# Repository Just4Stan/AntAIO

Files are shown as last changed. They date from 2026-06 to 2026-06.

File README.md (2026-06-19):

# AntAIO

Open-source **antweight / beetleweight combat-robot all-in-one** controller — an
ExpressLRS receiver, a 6-axis IMU, and a **triple brushed-DC ESC** on one tiny
board, in the spirit of the [Malenki Nano](https://turnabot.com/products/malenki-nano-integrated-6-channel-triple-electronic-speed-controller-receiver-combo). Built on
the **OpenRX-Lite** ELRS core (ESP32-C3 + SX1281, 2.4 GHz) and forked from
[`incutec-hw/OpenRX`](https://github.com/incutec-hw/OpenRX).

<p align="center">
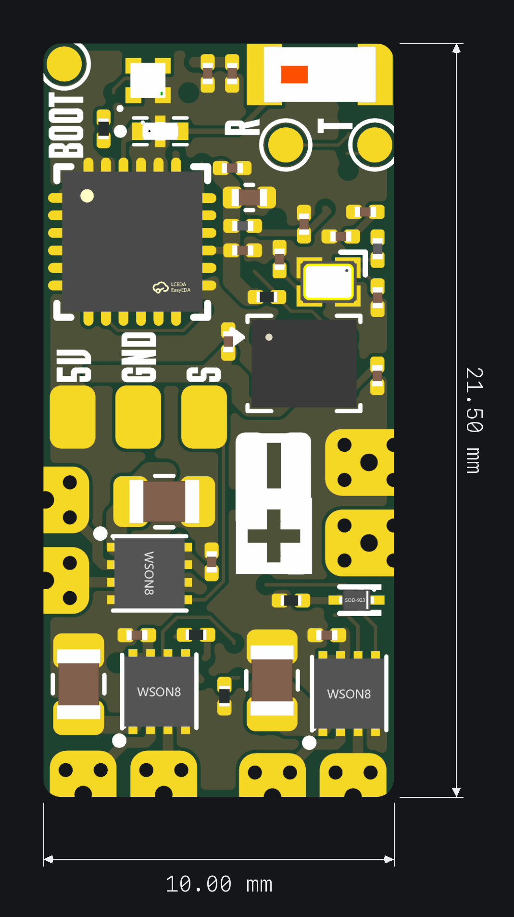
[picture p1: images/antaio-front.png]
AntAIO front
  
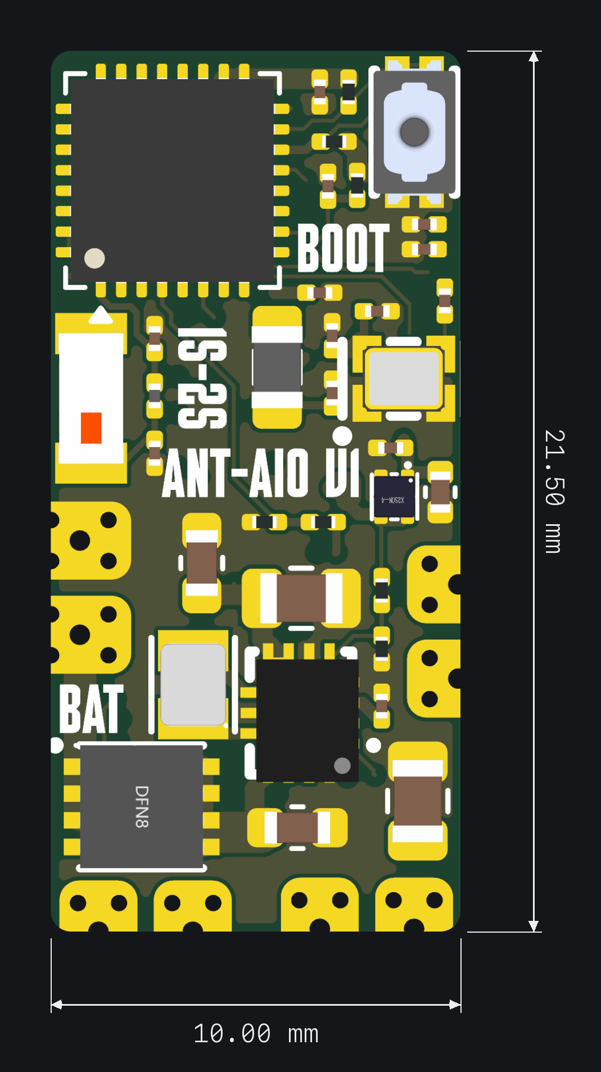
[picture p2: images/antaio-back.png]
AntAIO back
  
</p>

> [!WARNING]
> **Prototype — not validated, not fab-ready.** This board has open
> safety-critical issues (uncommanded drive-motor motion at power-up, and the
> programming interface shares pins with the motor outputs). It drives combat-robot
> motors **including a weapon** — do not build or power it without reading the
> review first. See **[hardware/REVIEW.md](hardware/REVIEW.md)** (full design
> review) and **[CHANGELIST.md](CHANGELIST.md)** (verified to-do list).

## What it is

A single **10.00 × 21.50 mm**, 6-layer board that replaces the usual *RX + 2 drive ESCs +
weapon ESC + gyro* stack of an antweight robot with one MCU-driven combo:

- **Radio link** — ExpressLRS 2.4 GHz (Semtech SX1281) for RC control + telemetry,
  plus the ESP32-C3's own Wi-Fi for OTA config.
- **Motion sensing** — LSM6DS3TR-C 6-axis IMU (gyro + accel) for heading-hold /
  self-right / melty-style control in firmware.
- **Three brushed-DC motor channels** — two drive + one weapon, each a TI DRV8212
  H-bridge fed directly from the battery.
- **Single-cell-friendly power** — buck-boost holds a 5 V rail as the pack sags
  under weapon load, with a linear 3.3 V logic rail and reverse-polarity protection.

Everything is controlled by the **ESP32-C3**: RC decode, mixing, gyro stabilization,
and the three motor PWM outputs all run on-chip.

## Architecture

```
            +BATT (1–2S LiPo)
              │
        Q2  AON7407  ── reverse-polarity P-FET
              ├─────────────► VM ─► DRV8212 ×3 ─► LEFT / RIGHT drive + WEAPON motors
              │
        U8  TPS63070 buck-boost ─► +5V ─► U4 TLV75533 LDO ─► +3V3 (logic)
                                                              │
   ┌──────────────────────────────────────────────────────────┤
   │                                                            │
 U1 ESP32-C3 ──SPI──► U3 SX1281 (2.4 GHz ELRS) ─► FL1 BPF ─► link antenna
   │            └────► U2 LSM6DS3TR-C IMU                 ESP Wi-Fi ─► AE1
   ├── 3× PWM ─► DRV8212 IN/EN  (U6 LEFT, U10 RIGHT, U11 WEAPON)
   ├── ADC ──── VSENSE (battery voltage divider)
   └── GPIO ──► WS2812B status LED (D1)
```

## Specifications

| Block | Part | Notes |
|---|---|---|
| **MCU** | Espressif **ESP32-C3FH4** (U1, QFN-32) | RISC-V, 4 MB embedded flash, 2.4 GHz Wi-Fi |
| **Link radio** | Semtech **SX1281** (U3) | 2.4 GHz, internal DC-DC, 52 MHz TCXO (OSC1), BPF FL1 (2450FM07D0034T) → link antenna |
| **IMU** | **LSM6DS3TR-C** (U2) | 6-axis accel+gyro, 4-wire SPI on the shared radio bus, dedicated CS |
| **Motor drivers** | 3× TI **DRV8212DSGR** | U6 = LEFT drive, U10 = RIGHT drive, U11 = WEAPON; PH/EN mode; VM = +BATT |
| **Buck-boost** | TI **TPS63070** (U8) | +BATT → 5 V; holds the rail across the 1S–2S sag range |
| **LDO** | **TLV75533PDQNR** (U4) | 5 V → 3.3 V logic rail |
| **Reverse protection** | **AON7407** P-FET (Q2) | on +BATT |
| **Status LED** | WS2812B (D1) | addressable RGB |
| **Battery** | **1–2S LiPo (≤ 8.4 V)** | DRV8212 VM is 12 V abs-max — **2S is the hard ceiling; 3S destroys the drivers** |
| **Board** | 10.00 × 21.50 mm, 6-layer | components both sides |

## I/O pads

Solder pads carry the external interface (silk in parentheses):

| Pad | Net | Function |
|---|---|---|
| `+` / `–` | `+BATT` / `GND` | Battery in (1–2S) |
| `5U` | `+5V` | 5 V buck-boost output (servo / accessory) |
| `GND` | `GND` | Ground |
| `S` | GPIO | Signal / spare control pad |
| `BOOT` | GPIO 9 | Hold low at power-up for UART download mode |
| `R` / `T` | UART0 RX / TX | Flashing & serial console (also the right-drive lines — flash with motor battery OFF) |

Motor outputs (OUT1/OUT2 of each DRV8212) and the weapon channel land on the large
copper pads along the board edge.

## ESP32-C3 pin map (as currently drawn)

| GPIO | Pin | Function | GPIO | Pin | Function |
|---|---|---|---|---|---|
| 0 | 4 | VSENSE (battery ADC) | 8 | 14 | WS2812 LED *(strap)* |
| 1 | 5 | Radio DIO1 | 9 | 15 | BOOT *(strap)* |
| 2 | 6 | IMU CS *(strap)* | 10 | 16 | WEAPON_EN |
| 3 | 8 | Radio BUSY | 18 | 25 | LEFT_PH *(USB D−)* |
| 4 | 9 | SPI MOSI | 19 | 26 | LEFT_EN *(USB D+)* |
| 5 | 10 | SPI MISO | U0RXD | 27 | RIGHT_PH |
| 6 | 12 | SPI SCK | U0TXD | 28 | RIGHT_EN |
| 7 | 13 | Radio NSS | GND/EP | 33 | GND |

> [!IMPORTANT]
> The drive-motor enables currently sit on the USB (GPIO18/19) and UART0
> (U0RXD/U0TXD) pins, which are driven **high at reset** — enabling both drive
> motors before firmware runs. The planned fix re-maps PH↔EN onto reset-quiet pins
> and gates the H-bridges behind a default-off arm switch. **Do not treat this pin
> map as final** — track it in [CHANGELIST.md](CHANGELIST.md).

## Flashing

- **UART:** hold `BOOT` low, power-cycle, flash over the `R`/`T` (U0RXD/U0TXD) pads
  **with the motor battery disconnected** (these pins also drive the right motor).
- **Wi-Fi OTA:** ExpressLRS SoftAP, after an initial wired flash.

The ELRS link runs upstream **ExpressLRS** (`Unified_ESP32C3_2400_RX`, ≥ 3.5.0).
The combat-robot mixing, IMU stabilization, and motor-PWM control are application
firmware layered on top (separate; not in this hardware repo).

## Repository

AntAIO began as a fork of [`incutec-hw/OpenRX`](https://github.com/incutec-hw/OpenRX)
— the **OpenRX-Lite** ELRS core (ESP32-C3 + SX1281) extended into a combat-robot
all-in-one. The other OpenRX receiver variants are not part of this repo.

```
AntAIO/
├── hardware/             AntAIO board: ELRS RX + IMU + triple brushed ESC
│   ├── AntAIO.kicad_{pro,sch,pcb}
│   ├── esp32c3_sx1281_lite.kicad_sch   ELRS core sub-sheet
│   ├── REVIEW.md         full design review (pin/datasheet/electrical)
│   └── DESIGN.md
├── shared/libs/          project-local KiCad symbols / footprints / 3D models
├── shared/elrs-targets/  ExpressLRS hardware-target JSON
├── datasheets/common/    local datasheet cache
├── images/               board renders
└── CHANGELIST.md         verified open / done items
```

KiCad 9/10; **project-local libraries only** (no global dependencies). Board renders
are produced with the shared `render_board.py` tool (vias + solder paste stripped,
transparent square).

## License

Hardware: **CERN Open Hardware Licence Version 2 — Strongly Reciprocal**
([CERN-OHL-S-2.0](https://ohwr.org/cern_ohl_s_v2.txt)). See [LICENSE](LICENSE).
Firmware: MIT.

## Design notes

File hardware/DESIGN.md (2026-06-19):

# AntAIO — design summary

Antweight / beetleweight combat-robot all-in-one: ExpressLRS 2.4 GHz receiver +
6-axis IMU + triple brushed-DC ESC on one 10.00 × 21.50 mm, 6-layer board. Built
on the OpenRX-Lite ELRS core (ESP32-C3 + SX1281).

For the full part list, pin map, I/O pads and architecture see the top-level
[README](../README.md). For the verified open/done design issues see
[REVIEW.md](REVIEW.md) and [CHANGELIST.md](../CHANGELIST.md).

## Board preview

| Front | Back |
|---|---|
| Front | Back |

## Schematic

- Root sheet: `AntAIO.kicad_sch` → ELRS core sub-sheet `esp32c3_sx1281_lite.kicad_sch`
- RF chain: `SX1281 RFIO → 2450FM07D0034 (FL1, 2.4 GHz BPF) → link antenna`
- ESP32-C3 Wi-Fi → AE1 (2450AT18A100E) for OTA config
- Power: AON7407 reverse P-FET → TPS63070 buck-boost (+5 V) → TLV75533 LDO (+3V3)
- Motors: 3× DRV8212 H-bridge (2 drive + 1 weapon), VM = +BATT

## Firmware

- ELRS link target: `Unified_ESP32C3_2400_RX` (≥ 3.5.0)
- Hardware JSON: `../shared/elrs-targets/OpenRX Lite 2400.json`
- Combat-robot mixing / IMU stabilization / motor PWM are application firmware on
  top of ELRS (separate; not in this hardware repo)

## Flash interface

- Pads: `5V` (or `5U`), `GND`, `R`/`T` (U0RXD/U0TXD)
- `BOOT`: hold low at power-up for UART download mode
- Wi-Fi OTA after the first wired flash
- **Flash with the motor battery disconnected** — `R`/`T` are also the right-drive lines

## Sourcing

LCSC basic/preferred parts where possible. Key RF/active parts:

- `C2651081` 2450FM07D0034 — 2.4 GHz bandpass filter (FL1)
- `C2151551` SX1281IMLTRT — link radio (watch stock for volume runs)
- DRV8212DSGR ×3 — brushed H-bridges
- TPS63070RNMR — buck-boost; TLV75533PDQNR — 3.3 V LDO

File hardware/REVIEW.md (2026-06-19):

I have all the data I need in the prompt. Let me synthesize the final report directly.

# OpenRX-Lite (AntAIO) — Final Design Review

**Board:** OpenRX-Lite extended to integrated antweight/beetleweight combat-robot controller (ELRS 2.4 GHz RX + IMU + triple brushed-DC ESC).
**Verdict:** **NOT READY FOR FAB.** Multiple confirmed SEV1 issues, two of them safety-critical (uncommanded drive-motor motion at every boot/reset) and two that make the board effectively un-flashable. One real wiring defect (floating radio ground). A redesign of the ESP32-C3 pin-mux/motor-control scheme is required, not just resistor edits.

---

## 1. Executive Summary

The sensing, radio, IMU, power-conversion, clock, and RF-front-end subcircuits are largely correct and match reference designs. The fatal problems are concentrated in the **ESP32-C3 pin-mux for the three motor drivers** and the **programming/debug path**:

- The 16-GPIO-class ESP32-C3 (QFN-32, FH4) is **out of pins**. To wire 3×(PH+EN) motor control plus SPI(4) + radio(NSS/BUSY/DIO1) + IMU_CS + LED + BOOT + VSENSE, the design consumed **both** the native USB-Serial/JTAG pins (GPIO18/19) **and** UART0 (U0RXD/U0TXD). The result: no usable flashing/console interface, and two motor-enable lines that are forced HIGH at reset by the chip's own internal pull-ups.
- This produces **uncommanded LEFT and RIGHT drive-motor motion on every power-up, reset, and flash** — a safety-critical failure on a combat robot. The WEAPON channel, by contrast, defaults safe.
- One genuine wiring defect: **SX1281 pin 5 (GND) is floating.**
- A 5 V intermediate rail that exists only to feed a 3.3 V LDO (efficiency + thermal SEV2), a 2S-max battery ceiling set by the DRV8212 (SEV2), missing local VM decoupling on the drivers (SEV2), and assorted SEV3 robustness items round out the list.

**Readiness: Block fab. Resolve the SEV1 cluster (pin-mux/programming/boot-safety) with a control-scheme redesign or larger-pin/expander part, fix the floating radio ground, then re-review.**

---

## 2. SAFETY-CRITICAL — Uncommanded Motor/Weapon Motion

The dominant hazard. Confirmed by adversarial verification. PH/EN mode is selected on all three drivers (MODE = +3V3, DRV8212 Table 8-2). In PH/EN mode, **EN=1 drives the H-bridge; EN=0 = brake/Hi-Z** (Table 8-4). The DRV8212 inputs have only an internal ~100 kΩ pulldown (RPD). The ESP32-C3's internal pulls at reset overpower that 100 kΩ:

| Channel | EN net | ESP pin / reset state | EN node voltage at reset | Result |
|---|---|---|---|---|
| **LEFT drive (U6)** | LEFT_EN = U1.26 = **GPIO19 (USB D+)** | USB_PU (~1.5 kΩ FS pull-up) | 3.3·100k/101.5k ≈ **3.25 V** ≫ VIH 1.45 V | **ENABLED.** LEFT_PH=GPIO18 has a 50 µs HIGH power-up glitch (Table 2-2) → defined forward-then-reverse twitch |
| **RIGHT drive (U10)** | RIGHT_EN = U1.28 = **U0TXD** | WPU 45 kΩ + output-enabled (UART idles driven HIGH) | 3.3·100k/145k ≈ **2.28 V** > VIH 1.45 V; or driven push-pull HIGH | **ENABLED.** RIGHT_PH=U0RXD idles HIGH → sustained **Forward drive** |
| **WEAPON (U11)** | WEAPON_EN = U1.16 = **GPIO10** | IE only, no pull (Table 2-1); 5 ns LOW glitch | DRV 100 kΩ pulldown wins → **~0 V** | **DISABLED — SAFE** |

So **both drive motors are commanded ON, uncommanded, during the multi-ms window between reset release and firmware GPIO config**, on every power-up, brown-out recovery, watchdog reset, and flash cycle. RIGHT is the worst: U0TXD is actively driven high and the UART bitstream toggles the bridge (DRV tPD 135 ns ≪ one 115200-baud bit). The WEAPON channel is the only correctly-defaulting one (GPIO10 has no internal pull; PH hard-tied to GND).

**Note (correcting the original audit):** WEAPON_EN does **not** float and is **not** the dominant hazard — the original "floating weapon" framing was inverted. The weapon is safe by construction; the **drive** channels are the hazard.

**Why the simple fix is insufficient:** a 10 kΩ external pulldown on LEFT_EN cannot beat the ~1.5 kΩ USB_PU on GPIO19; on RIGHT_EN, 10 kΩ vs 45 kΩ WPU still leaves ~0.6 V (above VIL 0.4 V) and loses entirely when UART0 drives push-pull. **No pulldown wins against these pins.**

**Required fix (hardware, Stan-owned):**
1. **Re-map LEFT_EN and RIGHT_EN (and their PH lines) off the USB D+/D- and UART0 console pins** onto plain GPIOs that have no internal reset pull-up (mirror the GPIO10/WEAPON pattern), with external pulldowns sized to dominate the DRV 100 kΩ.
2. **Hard-gate all three H-bridges' VM (or VCC) through a load switch that defaults OFF** until firmware asserts a separate "motors-armed" GPIO that itself powers up low. Treat "all bridges disabled at reset" as a hardware guarantee, not firmware-dependent. (DRV8212 VCC can be GPIO-gated as an arm path per datasheet 8.4.2.)
3. Add an explicit external pulldown on **WEAPON_EN** too (defense-in-depth on a weapon line), and ensure firmware brown-out + ELRS link-loss failsafe forces every EN low within one frame.

---

## 3. SEV1 — Showstoppers

### SEV1-A — No usable programming/debug interface (USB and UART0 both consumed by motors)
**Refs/nets:** LEFT_PH=GPIO18(U1.25), LEFT_EN=GPIO19(U1.26) → U6; RIGHT_PH=U0RXD(U1.27), RIGHT_EN=U0TXD(U1.28) → U10.
**What's wrong:** GPIO18/19 are the ESP32-C3's **only** native USB-Serial/JTAG D-/D+; U0RXD/U0TXD are the **only** UART0 console/download pins. Both pairs drive motor inputs. There is no USB connector and no clean UART header (only test points TP1/TP2 tapping the right-motor nets). Consequences: (1) USB programming and JTAG debug are permanently unavailable; (2) the only remaining flash path is BOOT-button + UART0 over TP1/TP2 — which is shared with the right-drive DRV8212, so flashing twitches the wheel; (3) Wi-Fi OTA cannot do the first flash or recover a bricked bootloader/partition.
**Evidence:** ESP32-C3 datasheet Table 2-4 (GPIO18/19 = USB_D-/D+), Section 2.3.x (default USB-Serial/JTAG); lite.json net members above; no USB/UART bridge in inventory.
**Fix:** Reserve a real programming interface — free GPIO18/19 for USB-Serial/JTAG and add a USB-C connector or D+/D- pads; move LEFT motor elsewhere. Realistically the part is out of GPIO, so the genuine fix is **collapse the motor-control scheme** (single-pin sign-magnitude PWM per driver, or an SPI/I²C motor-driver expander) to free UART0 and/or USB, or move to a higher-pin-count MCU.

### SEV1-B — Boot-time UART0 traffic drives the RIGHT motor
**Refs/nets:** RIGHT_EN=U0TXD(U1.28)→U10.5, RIGHT_PH=U0RXD(U1.27)→U10.6.
**What's wrong:** U0TXD is in the After-Reset state WPU + output-enabled (Table 2-1, fn 8): UART0 TX idles actively-driven HIGH and follows any UART init, holding RIGHT_EN high (and U0RXD/PH high → Forward). Covered quantitatively in §2; called out separately because it removes the serial console as well.
**Correction to original audit:** the default ROM-message channel on ESP32-C3 is the **USB-Serial/JTAG controller, not UART0** (Section 2.6.2 / Table 2-12; UART printing requires EFUSE_DIS_USB_SERIAL_JTAG=1). So "the ROM prints to U0TXD and toggles RIGHT" is the wrong mechanism — but the enable-forced-high conclusion holds via the After-Reset output-enabled-high state and any firmware UART0 init.
**Fix:** Never place a motor enable on the UART0 console TX. Re-map RIGHT off U0RXD/U0TXD; keep UART0 free for CRSF/console.

### SEV1-C — SX1281 pin 5 (GND) floating
**Refs/nets:** U3.5 → single-node net `unconnected-(U3-GND-Pad5)`.
**What's wrong:** Pin 5 is a **dedicated die ground** (SX1281 datasheet Table 2-1, p.17), distinct from the exposed pad (pin 25). It sits between XTA(4) and XTB(6) — the reference-oscillator/PA guard ground. It is the only U3 ground pin left open (13/20/21/23/24 and EP are on GND). Floating it removes the local oscillator/PA ground return and shield, degrading phase noise, spurs, and EMC. ERC missed it because the custom symbol's pin 5 electrical type is `unspecified`.
**Fix:** Tie U3.5 to the GND net/plane and re-pour. Scope the fix to **pin 5 only** — XTB(6) NC is correct TCXO behavior, do not "fix" it. Set the symbol pin to power_in/passive so ERC catches this class of omission in future.

---

## 4. SEV2 — Major

### SEV2-A — 5 V intermediate rail serves nothing but the 3.3 V LDO
**Refs/nets:** `+5V` = [C37.1, C38.1, C39.1, R16.2, TP15.1, U4.3, U4.4, U8.7]. Only U4 (TLV75533 LDO) is a real load. Motors run from +BATT; all logic from +3V3.
**What's wrong:** Chain is +BATT → TPS63070 buck-boost → 5.0 V → linear LDO → 3.3 V. The LDO burns (5.0−3.3)/5.0 = **34% of all logic-rail energy** for no functional reason. TPS63070 output range is 2.5–9 V (it can regulate 3.3–4.0 V directly). Setpoint confirmed 4.98 V via R16=52.3k/R17=10k, VFB=0.8 V.
**Fix:** Retarget the buck-boost to **~3.8–4.0 V** (R16 ≈ 40k with R17=10k) to keep the LDO in regulation while cutting its loss ~4×, or set 3.3 V and delete the LDO (but then the SX1281 loses the LDO's RF supply filtering). **Note:** the original "~3.5 V" suggestion is too low — TLV75533 dropout is 238 mV max @500 mA and it is spec'd at VIN ≥ VOUT+0.5 V, so 3.5 V starves regulation/PSRR.

### SEV2-B — TLV75533 (1×1 mm X2SON-4) thermal margin on the shared 3V3 rail
**Refs:** U4 OUT=+3V3 feeds U1, U3, D1, U2, U6/U10/U11 VCC. RθJA = 168.4 °C/W (DQN).
**What's wrong:** Dropping 1.7 V at sustained current pushes Tj past the 125 °C recommended max in an enclosed combat ambient: ~290 mA @25 °C or ~250 mA @45 °C breaches 125 °C; 335 mA (ESP Wi-Fi TX @100% duty, Table 4-7) → Tj ~121 °C @25 °C / ~141 °C @45 °C. Risk of thermal foldback → MCU/radio brownout.
**Corrections to original audit:** thermal shutdown is ~165 °C (not 150 °C); RθJA is steady-state, so the real driver is **sustained** Wi-Fi TX during OTA/SoftAP config, not motor PWM transients — during live combat the ELRS link is RX-dominated (~84 mA), so the direct in-match link-loss coupling is weaker than originally stated. Still a real margin issue.
**Fix:** Lower LDO Vin to ~3.8–4.0 V (Pd drops ~4–8×) per SEV2-A, or move to the 2×2 mm DRV SON-6 package (RθJA 100.2 °C/W) with a generous thermal-pad pour; cap WS2812 brightness/duty. Re-verify Tj < 125 °C at real ambient.

### SEV2-C — No local 0.1 µF VM ceramic on any of the three drivers
**Refs/nets:** +BATT (=VM) carries only bulk: C31–C34/C42 = 22 µF, C35 = 10 µF. No 100 nF anywhere on +BATT; no per-VM local HF cap.
**What's wrong:** DRV8212 Table 8-1 / VM pin description mandates a 0.1 µF low-ESR ceramic VM→GND **at each device** plus bulk. Bulk MLCC at distance cannot damp VM ringing from the H-bridge edges; risk of VM overshoot toward the 12 V abs-max and false OCP/UVLO trips.
**Fix:** Add one 0.1 µF (X7R, ≥16 V) VM→GND at pin 1/pin 4 of **each** of U6/U10/U11, placed immediately at the pins. Also ensure a dedicated 0.1 µF CVCC at each driver's pin 8 (required for the DSG package) is placed locally. (VM abs-max is exactly 12 V, not 11.)

### SEV2-D — DRV8212 VM caps the pack at 2S; 3S overvolts all three drivers
**Refs:** U6.1/U10.1/U11.1 = +BATT = VM (direct, only Q2 in series).
**What's wrong:** DRV8212 VM = 11 V recommended / **12 V abs-max**. 3S LiPo at 12.6 V exceeds abs-max → driver damage. 2S (8.4 V) is within rating. The DRV8212 is the single binding limit — TPS63070 (16/20 V) and AON7407 (−20 V VDS) are not. **Correction:** an earlier note citing "AON7407 30 V" is wrong; it is a 20 V part. Brushed-motor stall/regen flyback and hot-plug inrush (VM transient ramp abs-max 2 V/µs) can push VM above 12 V even on a compliant 2S pack — the +BATT rail currently has no TVS.
**Fix:** Hard-label/spec **2S max (8.4 V)** in README/DESIGN and silkscreen. Add a +BATT TVS with standoff < 12 V (e.g. ~8.5–9 V working, SMBJ-class) and confirm bulk handles inductive flyback. For 3S support the DRV8212 must be replaced (e.g. DRV8220, 18 V — but 1 Ω RDS(on)).

### SEV2-E — ESP32-C3 symbol mislabels pins 4/5 as XTAL_32K_P/N instead of GPIO0/GPIO1
**Refs:** U1 pin4 (symbol name "XTAL_32K_P") = VSENSE; pin5 ("XTAL_32K_N") = DIO1.
**What's wrong:** Netlist binds by pin number so the connection is electrically correct (pin4 = GPIO0/ADC1_CH0, pin5 = GPIO1/ADC1_CH1; the 32 kHz names are alternate functions, no 32 kHz crystal is used). But the symbol pin names are misleading and a real review/maintenance hazard — a future spin could "fix" a non-bug or wire a real 32 kHz crystal there.
**Fix:** Rename the symbol pins to GPIO0/GPIO1 (or "GPIO0/XTAL_32K_P") in OpenRX-Shared.kicad_sym. Metadata-only; no netlist change.

---

## 5. SEV3 — Minor / Robustness / EMC

- **L1 24 nH series inductor in the XTAL_P leg (X1 40 MHz):** non-standard and asymmetric vs the reference two-cap oscillator. XTAL_P=[L1.2,U1.30] → C1(15 pF)+X1.1; XTAL_N=[C3.1,U1.29,X1.3]. The series L (and placing C1 on the crystal side, not the pin) shifts effective load capacitance and can reduce startup/negative-resistance margin on a safety-critical board. **Fix:** remove L1 (0 Ω), put 15 pF symmetric load caps directly at both XTAL_P/XTAL_N per Espressif reference; if L1 is deliberate (EMC), make it symmetric and verify startup margin. Load caps C1=C3=15 pF are otherwise correct for the CL=10 pF crystal.

- **SX1281 NRESET shares the ESP32-C3 EN reset RC** (CHIP_EN = [C28.1, R5.1, U1.7, U3.3]; R5=10k, C28=1µF, ~10 ms POR). Radio cannot be reset independently of the MCU; a wedged radio needs a full ESP power-cycle. NRESET has an internal 50 kΩ pull-up so the wired POR is valid. **Downgraded from SEV2 → SEV3:** functionally fine for ELRS, watchdog-reset recovers it, no motor path. **Fix:** set SX1281 reset=−1 in the ELRS target JSON and document the shared-reset choice; optionally route NRESET to a spare GPIO.

- **WEAPON_EN relies only on the DRV 100 kΩ internal pulldown** — no external pulldown on a weapon-arming line. **Downgraded from SEV2 → SEV3:** the default state is robustly off (DRV VIH=1.45 V needs ~14.5 µA to false-trip; not credible from ESP Hi-Z leakage; GPIO10 power-up glitch is LOW). Still worth a dedicated 4.7k–10k external pulldown at U11.5 as combat-robot best practice.

- **VSENSE node has no anti-alias/decoupling cap and ~8.4 kΩ source impedance.** VSENSE=[R11.1(52.3k),R12.2(10k),U1.4]; taps raw +BATT (shared with motor VM). High-Z + no filter → jittery ADC, possible nuisance LVC/failsafe trips. **Fix:** add 10–100 nF VSENSE→GND at the ADC pin (forms RC with the divider). Divider ratio 0.1605 is correct (2S→1.35 V, in ADC range).

- **TPS63070 COUT may dip below the 40 µF-effective floor after DC-bias derating.** C37(10µF/0603)+C38(22µF/0805)+C39(22µF/0805) = 54 µF nominal → ~30–40 µF effective at 5 V bias. **Fix:** match the datasheet 3×22 µF reference (swap C37 10µF→22µF) or use better DC-bias-retaining parts. Milder if rail is retargeted to ~3.8 V.

- **+BATT bulk thin / verify cap voltage rating.** ~120 µF nominal (heavily derated to ~40–80 µF effective at 8.4 V) shared by three H-bridges. Confirm C45783/C92487 are ≥16 V (preferably 25 V) rated for inductive transients; consider adding a low-ESR polymer/electrolytic at the +BATT entry for the weapon transient.

- **WS2812B (D1) VDD on +3V3 is below the 3.5 V datasheet minimum** (spec 3.5–5.5 V). 3.3 V is out-of-spec; clones usually light but color accuracy/internal-regulator behavior is unguaranteed. **Fix:** move D1 VDD to +5V — DIN direct from 3.3 V GPIO8 still meets VIH=2.8 V, no level shifter needed. *(Note: this is listed SEV2 in the source audit; rated SEV3 here as it is a status LED, not function-critical — but it is genuine out-of-spec operation, fix it.)*

- **WS2812B DIN has no series damping resistor.** R3 (10k to +3V3) is the GPIO8 boot strap, not a series term. Fine for a single short-stub LED; add ~47–100 Ω series in the DIN trace if EMI/edge integrity matters later (keep the 10k strap on the GPIO8 side).

- **VR_PA decoupled by single 10 nF (C27) vs reference 2×10 nF; DCC_FB second cap 10 nF (C26) vs reference 100 nF.** Add a parallel cap on VR_PA and change C26 → 100 nF to match the Semtech reference. Low priority.

- **TCXO (OSC1) VCC has no ferrite/dedicated local bypass; powered straight off the noisy shared +3V3.** SX1281 TCXO app note (Fig 15-3) shows a ferrite bead + 100 nF to keep digital/switcher noise off the 52 MHz reference (phase noise directly degrades RX). **Fix:** add a 600 Ω@100 MHz bead + local 100 nF at OSC1 VCC.

- **WSON-8 DRV8212 thermal ceiling ~2 A/channel continuous.** I²R = I²·0.28 Ω; at 3 A → ~2.5 W → TSD. OCP trips at 4 A (1.7 ms retry). Weapon/drive stall will OCP-cycle/TSD. **Fix:** dense thermal-via field under each EP, firmware current/PWM limits ~2 A/channel; for the weapon consider paralleling half-bridges (8 A) — requires Hi-Z MODE redesign.

- **L6 (1.5 µH 2016) Isat headroom thin vs 3.6 A switch limit** — acceptable only because the real 5 V load is light. Confirm Isat ≥ ~2.5 A when sourcing.

---

## 6. ELRS RF Front-End — Open Items (review-flagged, schematic-scope)

- **AE2 antenna BOM/doc mismatch + no matching network.** Netlist value for AE2 is `2450AT18A100E` (same as the Wi-Fi AE1), but README/CLAUDE.md state the Lite link antenna is the Molex **47948-0001**. Reconcile BOM vs docs. Net-(FL1-OUT)=[AE2.1, FL1.3] has **no matching components and no retune pads**, while the 2450AT18A100E datasheet explicitly requires a match (RL only 9.5 dB min). **Fix:** decide the real part and make the value field match; add a pi/L match footprint (0201 placeholders) on the FL1-OUT→antenna node; budget the loss into the link budget. *(Worth resolving but not a SEV1 — link still functions.)*

- **RFIO → FL1 direct (no series match/DC-block).** Acceptable: FL1's IN port is a 40 Ω chipset-matched port intended to mate with SX1281 RFIO directly, and the 2450FM07 is internally DC-blocked. Confirm against the Johanson app note / ELRS target, keep RFIO→FL1 trace short and impedance-controlled, and add FL1 IL (0.75–1.0 dB) to the link budget. If FL1 DC-pass is ever unconfirmed for a future grounded-feed antenna, add a series 100 pF C0G.

- **Two 2.4 GHz radios (ELRS link + ESP Wi-Fi), separate antennas, no RF switch.** Standard ELRS-RX approach; coexistence is firmware time-shared (Wi-Fi OTA-only). Maximize AE1/AE2 isolation in layout; document Wi-Fi as OTA-only in DESIGN.md.

---

## 7. Unconnected-Pin Disposition

| Pin(s) | Disposition |
|---|---|
| U1.19–24 (SPIHD/WP/CS0/CLK/D/Q) | **NC — correct.** In-package flash on ESP32-C3FH4; must not route externally |
| U2.4 INT1, U2.9 INT2 (IMU) | **NC — acceptable.** Polling-only; no spare GPIO for DRDY. For melty/heading-hold a hardware DRDY would give deterministic sampling — note as limitation |
| U2.10, U2.11 (IMU NC) | **NC — correct.** Datasheet: leave electrically unconnected, keep pads soldered |
| U3.5 (GND) | **DEFECT — must tie to GND.** See SEV1-C |
| U3.6 (XTB) | **NC — correct.** TCXO drives XTA via C19; second crystal terminal unused |
| U3.9 DIO2, U3.10 DIO3 | **NC — correct.** Optional radio DIO, unused by ELRS |
| U8.2 (PG) | **NC — acceptable.** Open-drain power-good; could optionally gate driver arm |
| D1.1 (DOUT) | **NC — correct.** Single WS2812, end of chain |
| AE1.2, AE2.2 | **NC — correct.** Single-feed chip-antenna ground/keep-out pads |
| GPIO20/GPIO21 (U0RTS/U0CTS) | **Unused — the only free pins.** Repurposing these is the lever to fix the pin-budget/programming-path problem |

---

## 8. Confirmed-Correct / INFO

- **Strapping pins GPIO2/GPIO8/GPIO9** all correctly biased (10k pull-ups to +3V3; BOOT button to GND): GPIO2(IMU_CS)=1, GPIO8(LED)=1, GPIO9(BOOT)=1 idle / 0 pressed → clean SPI boot, download only on button. R2 doubles as IMU CS idle-high and the GPIO2 strap; R3 doubles as the GPIO8 strap. **Ensure R2/R3/R4 are populated.**
- **CHIP_EN RC** = 10k(R5) × 1µF(C28) ≈ 10 ms POR, satisfies tSTBL/tRST(50 µs), not floating (datasheet requirement met).
- **VSENSE on GPIO0/ADC1_CH0** — valid ADC pin (ADC1 works with Wi-Fi on); divider 0.1605 keeps 1S–3S in the ATTEN3 0–2500 mV window; cell count bounded by DRV8212 VM, not the ADC.
- **LNA_IN Wi-Fi pi-match** (C22 1.2pF shunt / L2 2.5nH series / C21 1.2pF shunt) → AE1: canonical ESP32-C3 single-ended topology; tune on VNA.
- **L3 = Murata LQP03TN2N0B02D (2.0 nH RF inductor), correct** — the +3V3→L3→C25(1µF)→VDD3P3(pins 2,3) topology matches the Espressif analog/RF (Wi-Fi PA) reference. The "2N0" MPN decodes to 2.0 nH; **not** a mislabeled ferrite bead.
- **SX1281 SMPS mode** correct (VDD_IN tied to DCC_FB, L4 15µH on DCC_SW, 470nF on DCC_FB). **TCXO front-end** correct (52 MHz clipped-sine → C19 1nF AC-couple → XTA; XTB NC). **SPI shared bus** correct: MISO/MOSI/SCK shared SX1281+IMU+ESP, dedicated CS each, NSS 10k pull-up, IMU CS 10k pull-up — no contention, both slaves tri-state MISO when deselected (Semtech Fig 9-5 endorses this topology).
- **LSM6DS3TR-C** fully correct: 4-wire SPI not swapped (SDI←MOSI, SDO→MISO, SPC←SCK, CS←IMU_CS); aux-I²C SDx/SCx tied to GND (datasheet Mode-1); VDD/VDDIO on +3V3 with 100nF each (C15/C18); all node voltages within 4.8 V abs-max.
- **FL1 2450FM07D0034T** orientation correct (IN 40Ω→RFIO, OUT 50Ω→antenna, both GND pads grounded, internally DC-blocked).
- **Q2 AON7407 reverse-polarity P-FET** topology and gate network correct: source on battery B+, drain on +BATT load; R13 10k gate pulldown turns it on in normal use; **U7 6.2 V Zener correctly clamps VGS within the ±8 V abs-max** (required at 2S where unclamped VGS would be 8.4 V). *(See §9 — the "FET is backwards" claim is one investigator's contested finding.)*
- **5V→3V3 sequencing** correct (LDO EN tied to +5V, so 3V3 cannot precede 5V). TPS63070 EN via R15 100k to +BATT (always-on, within 20 V abs-max), PS/SYNC to GND via R14 (forced PWM, low ripple — good for RF), FB R16/R17 = 4.98 V, Vaux 100 nF.
- **DRV8212 MODE=+3V3 (PH/EN)** consistent on all three; **WEAPON PH=GND** is a sensible fixed-direction single-quadrant weapon drive; **EP→GND** on all three; OUT routing to motor pads correct.

---

## 9. Investigated — Not an Issue (dropped per verification)

- **"LEFT_PH GPIO18 50 µs glitch is a standalone SEV1 uncommanded-motion path."** **INVALID / demoted to INFO.** Per DRV8212 Table 8-4, EN=0 forces brake→Hi-Z with PH as don't-care, and PH has its own internal pulldown — a PH glitch alone causes no motion. The real hazard is the EN line (covered in §2). The 50 µs glitch only sets direction once EN is (separately) asserted.
- **"VDD_SPI (pin18) tied to +3V3 is a SEV2 topology/labeling risk."** **INVALID / demoted to INFO.** For the embedded-flash FH4, VDD_SPI is a backup-power **input** whose recommended input range (3.0/3.3/3.6 V) equals the rail; tying to +3V3 is the standard Espressif approach used in every C3 module. The "internal-LDO-shorted" scenario requires an off-package flash that does not exist (pins 19–24 unbonded). Residual: the symbol's `power_out` type for pin 18 is cosmetically imprecise (may trip a benign ERC warning) — optionally set to power_input/passive.
- **"Analog VDD3P3/VDDA decoupling SEV2 — L3 is a mislabeled ferrite bead."** **INVALID.** L3 is a genuine 2.0 nH RF inductor (Murata LQP03TN2N0B02D, see §8). The topology is the Espressif analog/RF reference. The only residue is a routine layout reminder (place a 100 nF adjacent to pins 2/3, 11, 17, 31/32) — INFO, not SEV2.
- **Q2 "FET is wired backwards / body diode defeats reverse protection" (one subcircuit investigator).** **Contested / not carried as a finding.** The dedicated Q2 pin-level audit and the power-tree audit both conclude the AON7407 orientation (source→battery B+, drain→+BATT load) with the R13 pulldown and 6.2 V Zener clamp is the correct high-side P-FET reverse-polarity/load-switch topology that blocks on reverse-connect. Given the majority pin-level verdict, this is not flagged as a defect — but it is the **one disagreement among reviewers**: before fab, Stan should confirm Q2 source/drain orientation against the AON7407 body-diode direction on the actual symbol/footprint, since a genuinely reversed P-FET would pass reverse current through the body diode. Low effort to verify, high consequence if wrong.

---

### Priority fix order
1. **Re-architect ESP32-C3 motor control** to free USB (GPIO18/19) and UART0 — single-pin sign-magnitude PWM or SPI/I²C motor expander, or larger MCU. This resolves SEV1-A/B and the §2 boot-drive hazard simultaneously.
2. **Hardware motor-disable / arm load switch** defaulting OFF (VM or VCC gated), plus external pulldowns on all three EN lines.
3. **Tie SX1281 pin 5 to GND** (SEV1-C).
4. Retarget buck-boost to ~3.8–4.0 V (SEV2-A/B); add per-driver 0.1 µF VM + VCC caps (SEV2-C); 2S-max label + +BATT TVS (SEV2-D); fix the symbol pin names (SEV2-E).
5. SEV3 cleanup: remove/symmetrize L1, VSENSE filter cap, WS2812 on +5V, TCXO bead, COUT match, reconcile AE2 BOM/docs + add match pads.

**Relevant files:** `hardware/AntAIO.kicad_sch`, `hardware/esp32c3_sx1281_lite.kicad_sch`, symbol library `shared/libs/OpenRX-Shared.kicad_sym` (SX1281 pin-5 type, ESP32-C3 pin4/5 names).

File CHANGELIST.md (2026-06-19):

# AntAIO — Verified Change List

1–2S antweight AIO (ESP32-C3 + SX1281 ELRS/ESPNOW, 4×N20 tank drive via 2 paired
DRV8212 + 1 weapon DRV8212, LSM6DS3 IMU). Forked from OpenRX-Lite.

Status as of 2026-06-18. Items below are **verified against the netlist** — open
items still need doing in KiCad; "already fixed" is for reference.

---

## OPEN — to do (in KiCad)

### 🔴 Critical
- [ ] **Swap PH↔EN on both drive drivers (boot-safety — motors run at power-on otherwise).**
  EN currently sits on pins driven HIGH at reset (USB D+ pull-up / UART TX), so the
  bridges enable before firmware. Move EN to the quiet pins, PH to the driven pins:
  - Left (U6):  **IN2/EN → GPIO18 (D-)**, **IN1/PH → GPIO19 (D+)**   *(swap of today's 19/18)*
  - Right (U10): **IN2/EN → GPIO20 (U0RXD)**, **IN1/PH → GPIO21 (U0TXD)** *(swap of today's 21/20)*
  - Weapon (U11) already safe (EN=GPIO10, no pull) — leave it.
  - Update the firmware target pin map to match after the swap.
- [ ] **Tie SX1281 (U3) pin 5 GND → GND** (currently floating; ERC missed it — pin type unspecified).

### 🟠 Important
- [ ] **Add a local 0.1 µF on each driver's VM and VCC** — U6, U10, U11 (6 caps total),
  placed at the pins. Today only distant bulk on +BATT.
- [ ] **Add a TVS on +BATT** (~9 V standoff, <11 V clamp) for inductive spikes / mis-plug.
  DRV8212 VM is 2S-max — **document the board as 2S-max** (3S destroys all drivers).
- [ ] **Add 2 UART flashing pads: GPIO20 (U0RXD) + GPIO21 (U0TXD).** With the existing
  BOOT button + GND (TP7) + a 3V3 tap, that's a full flash path (hold BOOT, power-cycle).
  Flash with motor battery OFF — these pins are also the right-drive lines.

### 🟡 Verify / minor
- [ ] **Add 100 nF on the VSENSE node → GND** (GPIO0). Today unfiltered + ~8 kΩ high-Z into the ADC.
- [ ] **Reconcile the ELRS antenna (AE2)** — netlist has `2450AT18A100E`, docs say Molex
  `47948-0001`, and there's **no match network**. Pick one and add the matching network.
- [ ] (cosmetic) ESP32-C3 symbol labels pins 4/5 as `XTAL_32K` — they are GPIO0/GPIO1. Relabel for clarity.

---

## Already fixed (verified in schematic)
- ✅ P-FET Q2 orientation correct (battery→Source, loads→Drain, Zener clamp on battery side).
- ✅ 3× DRV8212 placed + wired (2 drive paired, 1 weapon); MODE→3V3 (PH/EN); weapon PH→GND.
- ✅ SX1281 NRESET → CHIP_EN (radio resets with MCU; `radio_rst` undefined in firmware — confirmed safe in ELRS source).
- ✅ IMU SDO/SA0 → MISO (was on MOSI); shared SPI bus, CS=GPIO2, NSS=GPIO7.
- ✅ Power tree: AON7407 reverse P-FET → TPS63070 buck-boost → 5 V → TLV75533 LDO → 3V3.
  FB 52.3k/10k ≈ 5.0 V; EN pull-up; PS/SYNC→GND (forced PWM); VAUX cap; FB2→GND (datasheet-OK).
- ✅ VSENSE divider 52.3k/10k → GPIO0 (ADC). NSS pull-up (10k→3V3) on GPIO2 strapping.

## Decisions (do NOT change)
- **Keep the 5 V rail at 5 V.** It powers the servo/BLDC weapon output — do not retarget the
  buck-boost to ~4 V (the ~34 % LDO loss is small in absolute terms at ~0.4 A logic).
- **LDO thermal:** fine for ELRS (WiFi off). For **ESPNOW mode** (continuous WiFi) the 1×1 mm
  TLV75533 runs warm dropping 5→3.3 V — give it copper pour; no part change needed.
- **VSENSE stays on GPIO0, IMU_CS on GPIO2** — GPIO0 is the only non-strapping ADC pin; a divider
  on the GPIO2 strapping pin would break boot.

## Reference — final 15-pin map (ESP32-C3)
`0`=VSENSE · `1`=DIO1 · `2`=IMU_CS(+pull-up) · `3`=BUSY · `4`=MOSI · `5`=MISO · `6`=SCK ·
`7`=NSS · `8`=WS2812 · `9`=BOOT · `10`=WEAPON_EN · `18/19`=Left EN/PH* · `20/21`=Right EN/PH* ·
SX1281 RST→CHIP_EN. *(EN/PH order flips after the boot-safety swap above.)*

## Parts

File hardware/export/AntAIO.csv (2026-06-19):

Reference | Qty | Value | DNP | Exclude from BOM | Exclude from Board | Footprint | Datasheet | LCSC Part | LCSC Part_1 | LCSC
AE1 | 1 | 2450AT18A100E |  |  |  | OpenRX-Shared:ANT-SMD_L3.2-W1.6 | https://lcsc.com/product-detail/RF-Antenna_JOHANSON_2450AT18A100E_2450AT18A100E_C89334.html | C89334 |  | C89334
AE2 | 1 | 47948-0001 |  |  |  | OpenRX-Shared:ANT-SMD_47948-0001 | https://lcsc.com/product-detail/RF-Antenna_MOLEX_47948-0001_47948-0001_C152351.html | C152351
C1,C3 | 2 | 15pF |  |  |  | Capacitor_SMD:C_0201_0603Metric |  | C85891 |  | C85891
C4,C10,C15,C23,C25,C28 | 6 | 1uF |  |  |  | Capacitor_SMD:C_0201_0603Metric |  | C76935 |  | C76935
C5,C6,C9,C12,C13,C14,C17 | 7 | 100nF |  |  |  | Capacitor_SMD:C_0201_0603Metric |  | C76939 |  | C76939
C8,C11,C16 | 3 | 10uF |  |  |  | Capacitor_SMD:C_0402_1005Metric |  | C15525 |  | C15525,C76991
C19 | 1 | 1nF |  |  |  | Capacitor_SMD:C_0201_0603Metric |  | C66942 |  | C66942
C20 | 1 | 470nF |  |  |  | Capacitor_SMD:C_0201_0603Metric |  | C85926 |  | C85926
C21,C22 | 2 | 1.2pF |  |  |  | Capacitor_SMD:C_0201_0603Metric |  |  |  | C85895
C24,C26,C27 | 3 | 10nF |  |  |  | Capacitor_SMD:C_0201_0603Metric |  | C2168164 |  | C2168164
D1 | 1 | XL-1010RGBC-WS2812B |  |  |  | OpenRX-Shared:LED-SMD_4P-L1.0-W1.0-TL_XL-1010RGBC-WS2812B |  | C5349953
FL1 | 1 | 2450FM07D0034T |  |  |  | OpenRX-Shared:FILTER-SMD_4P-L1.0-W0.5-L | https://www.lcsc.com/datasheet/C2651081.pdf | C2651081 | C2651081
L1 | 1 | 24nH |  |  |  | Inductor_SMD:L_0201_0603Metric |  | C206441 |  | C206441
L2 | 1 | 2.5nH |  |  |  | Inductor_SMD:L_0201_0603Metric |  |  |  | C206435
L3 | 1 | 2.0nH |  |  |  | Inductor_SMD:L_0201_0603Metric |  |  |  | C86125
L4 | 1 | 15uH |  |  |  | Inductor_SMD:L_0805_2012Metric
OSC1 | 1 | OW7EL89CENUNFAYLC-52M |  |  |  | OpenRX-Shared:OSC-SMD_4P-L2.0-W1.6-BL_TXC_7Z |  | C22434896 |  | C22434896
R2,R3,R4,R5 | 4 | 10k |  |  |  | Resistor_SMD:R_0201_0603Metric |  | C106225 |  | C106225
TP1 | 1 | RX |  |  |  | OpenRX-Shared:SolderPad_1.2x2.0mm
TP2 | 1 | TX |  |  |  | OpenRX-Shared:SolderPad_1.2x2.0mm
TP3 | 1 | 5V |  |  |  | OpenRX-Shared:SolderPad_1.2x2.0mm
TP4 | 1 | GND |  |  |  | OpenRX-Shared:SolderPad_1.2x2.0mm
TP5 | 1 | BOOT |  |  |  | OpenRX-Shared:SolderPad_1.2x2.0mm
U1 | 1 | ESP32-C3 |  |  |  | Package_DFN_QFN:QFN-32-1EP_5x5mm_P0.5mm_EP3.7x3.7mm | https://www.espressif.com/sites/default/files/documentation/esp32-c3_datasheet_en.pdf
U2 | 1 | TLV75533PDQNR |  |  |  | OpenRX-Shared:X2SON-4_L1.0-W1.0-P0.65-TL-EP |  | C2861882 |  | C2861882
U3 | 1 | SX1281IMLTRT |  |  |  | OpenRX-Shared:QFN-24_L4.0-W4.0-P0.50-TL-EP2.6 |  | C2151551 |  | C2151551
X1 | 1 | CJ17-400001010B20 |  |  |  | OpenRX-Shared:CRYSTAL-SMD_4P-L1.6-W1.2-BL |  | C2875272 |  | C2875272

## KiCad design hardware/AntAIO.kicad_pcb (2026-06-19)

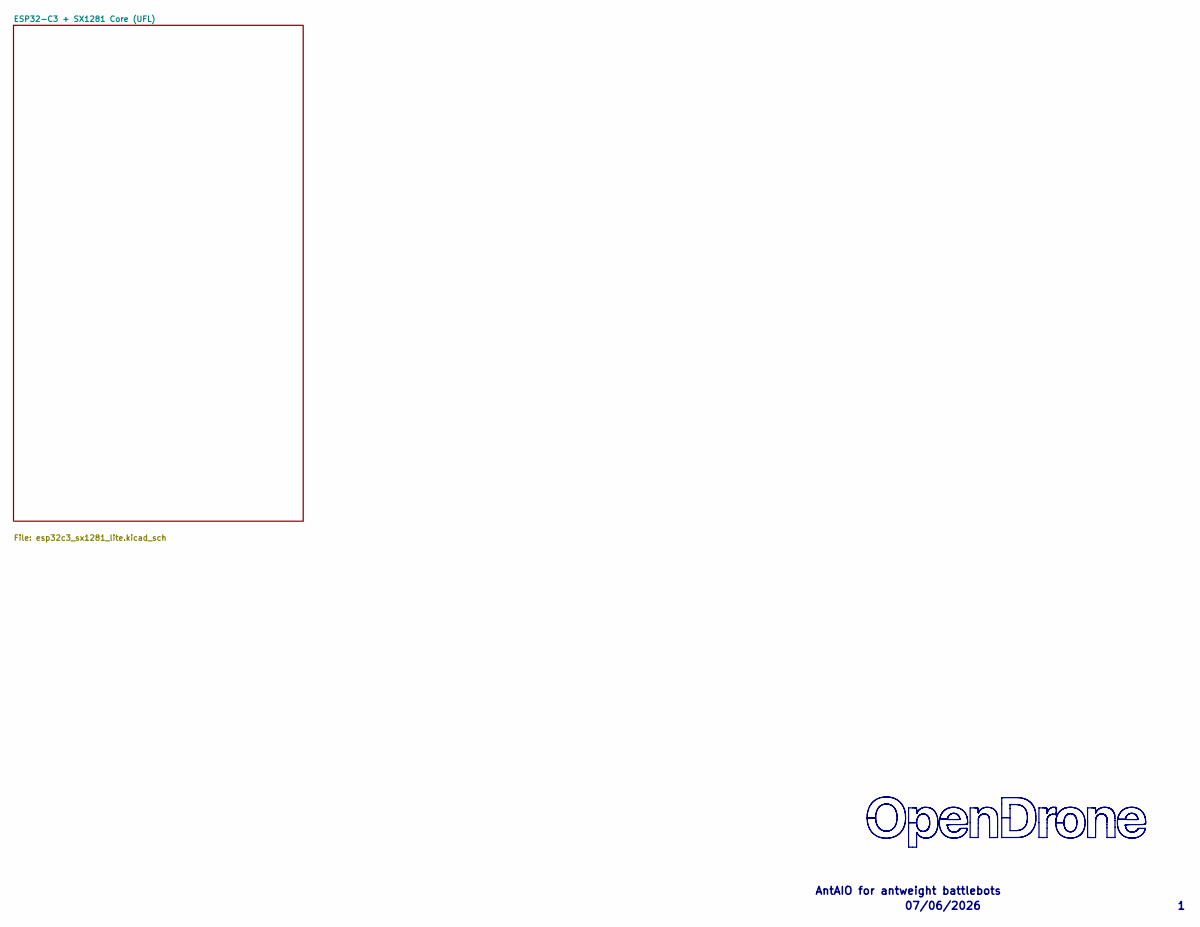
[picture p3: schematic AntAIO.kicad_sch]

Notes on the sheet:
07/06/2026
AntAIO for antweight battlebots

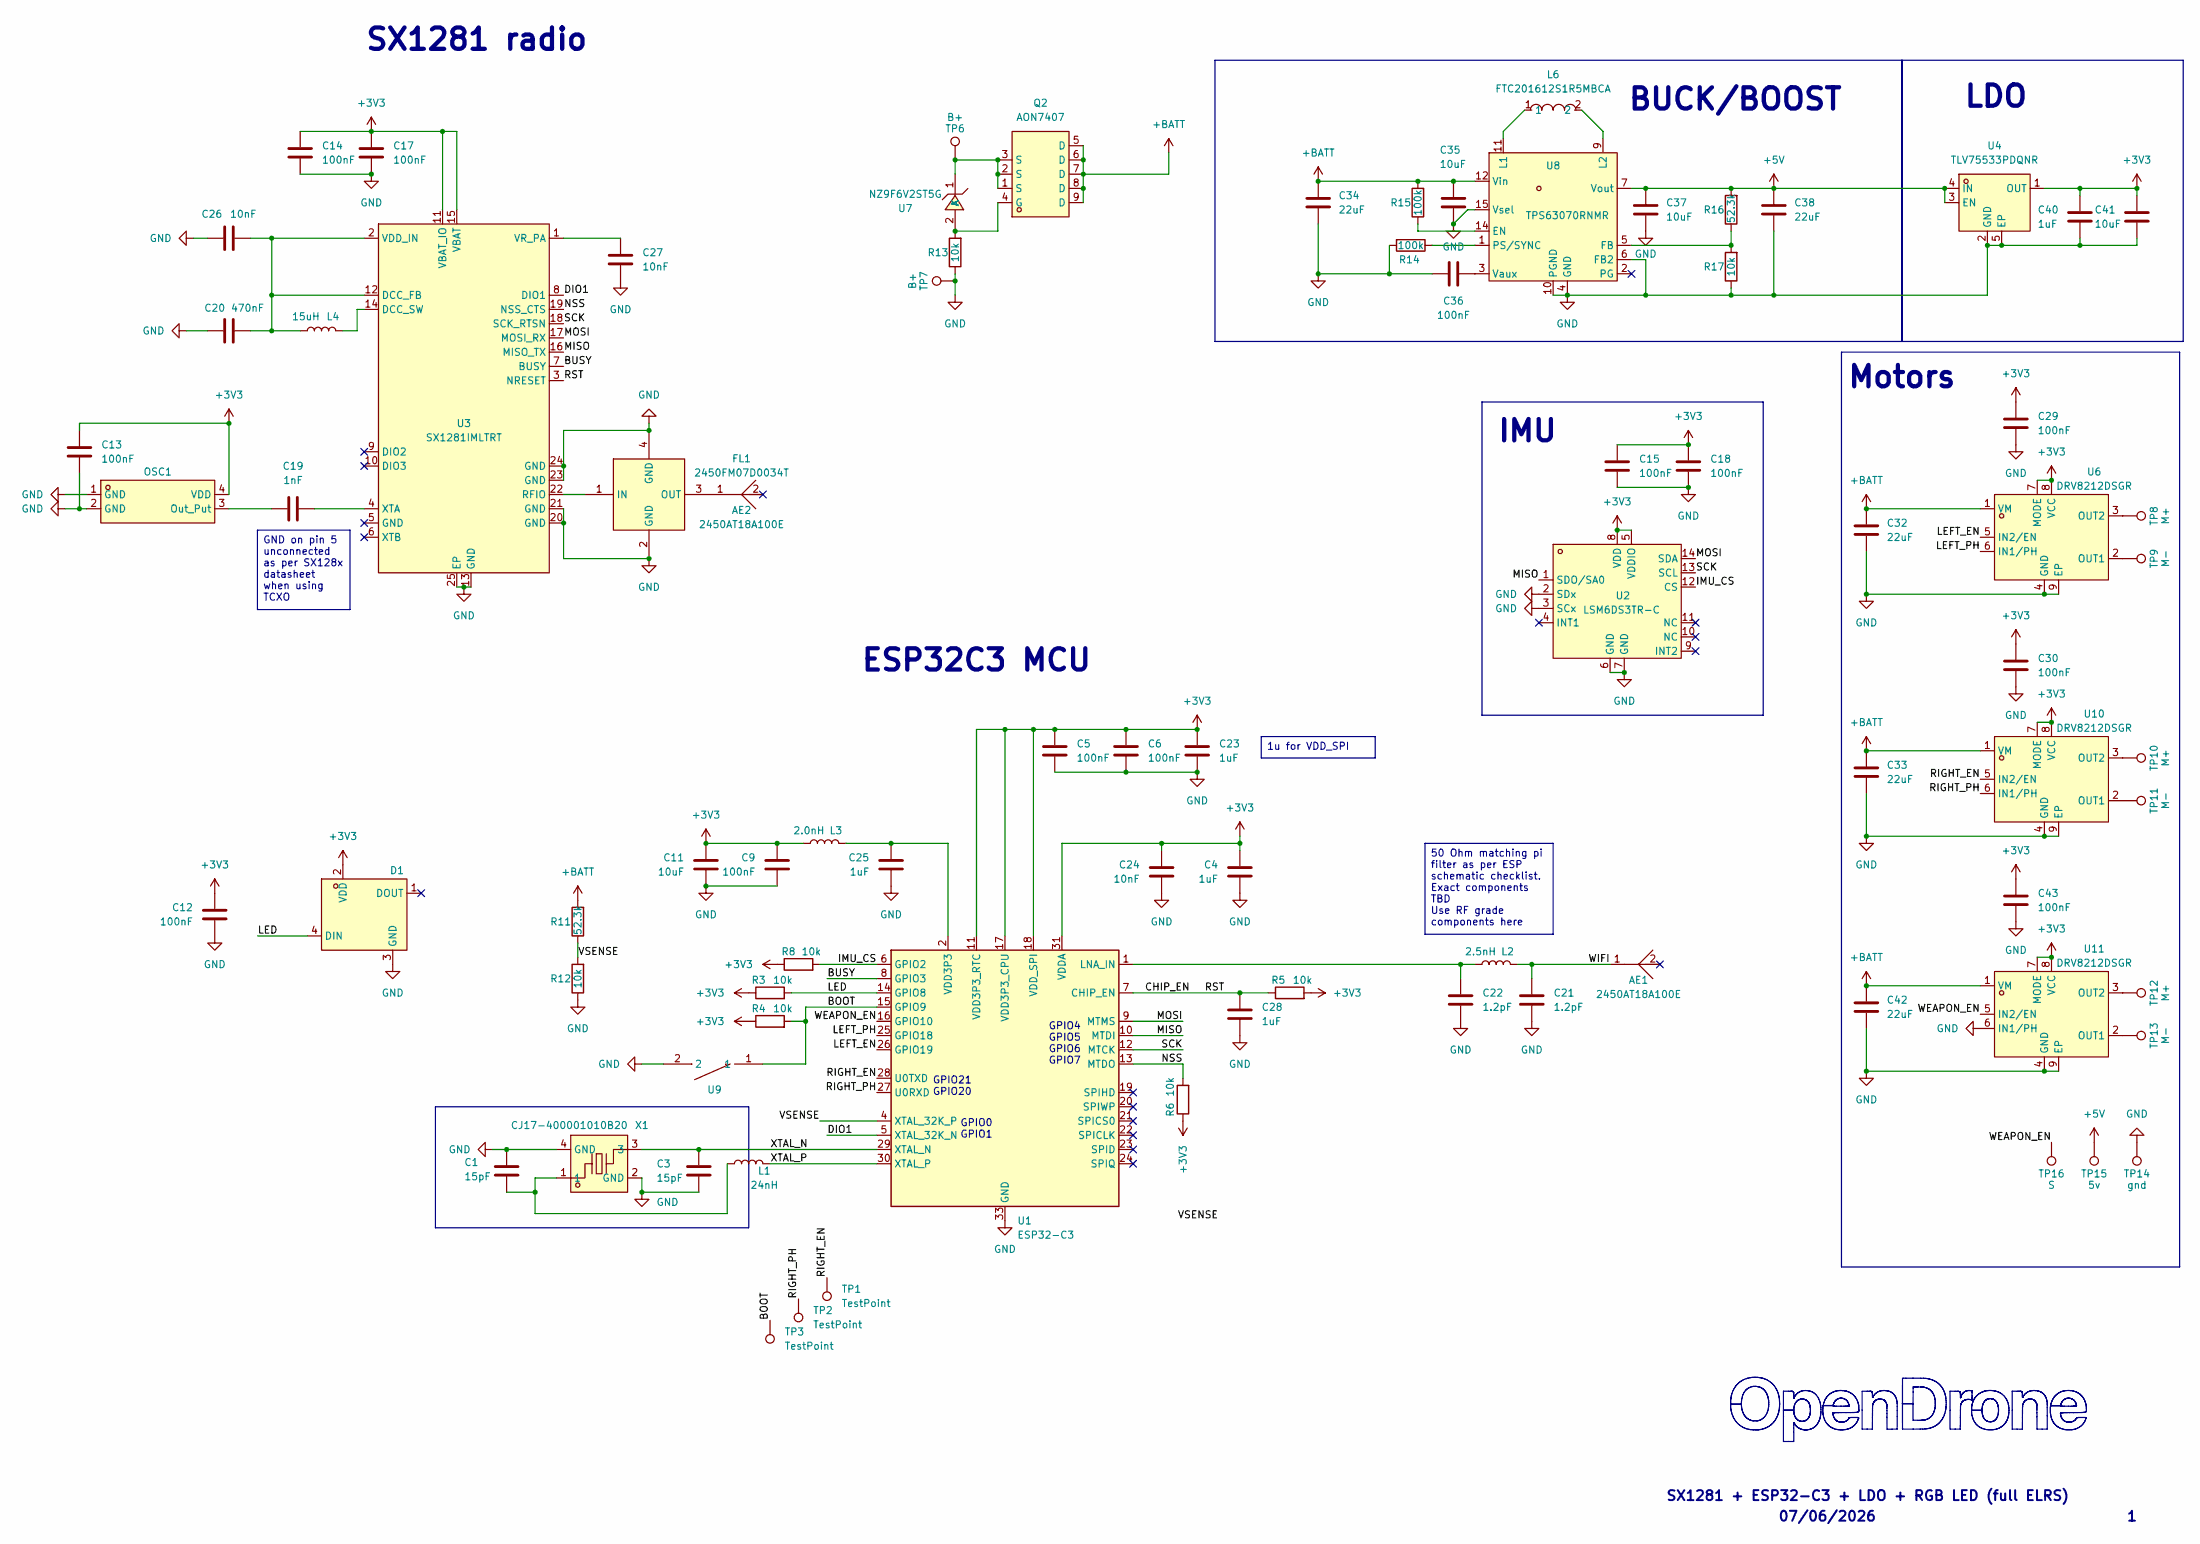
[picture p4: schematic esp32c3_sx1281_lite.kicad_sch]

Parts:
AE1, AE2: 2450AT18A100E; ANT-SMD_L3.2-W1.6; LCSC Part C89334
C1, C3: 15pF; C_0201_0603Metric; LCSC C85891
C4, C23, C25, C28, C40: 1uF; C_0201_0603Metric; LCSC C76935
C5, C6, C9, C12, C13, C14, C15, C17, C18, C29, C30, C36, C43: 100nF; C_0201_0603Metric; LCSC C76939
C11: 10uF; C_0402_1005Metric; LCSC C76991
C19: 1nF; C_0201_0603Metric; LCSC C66942
C20: 470nF; C_0201_0603Metric; LCSC C85926
C21, C22: 1.2pF; C_0201_0603Metric; LCSC C85895
C24, C26, C27: 10nF; C_0201_0603Metric; LCSC C2168164
C32, C33, C34, C38, C42: 22uF; C_0805_2012Metric; LCSC C45783
C35, C37: 10uF; C_0603_1608Metric; LCSC C92487
C41: 10uF; C_0402_1005Metric; LCSC C15525
D1: XL-1010RGBC-WS2812B; LED-SMD_4P-L1.0-W1.0-TL_XL-1010RGBC-WS2812B; LCSC Part C5349953
FL1: 2450FM07D0034T; FILTER-SMD_4P-L1.0-W0.5-L; MPN 2450FM07D0034T; LCSC Part C2651081
L1: 24nH; L_0201_0603Metric; LCSC C206441
L2: 2.5nH; L_0201_0603Metric; LCSC C206435
L3: 2.0nH; L_0201_0603Metric; LCSC C86125
L4: 15uH; L_0805_2012Metric
L6: FTC201612S1R5MBCA; IND-SMD_L2.0-W1.6; MPN FTC201612S1R5MBCA; LCSC Part C5832350
OSC1: OW7EL89CENUNFAYLC-52M; OSC-SMD_4P-L2.0-W1.6-BL_TXC_7Z; LCSC Part C22434896
Q2: AON7407; DFN-8_L3.0-W3.0-P0.65-BL; MPN AON7407; LCSC Part C176756
R3, R4, R5, R6, R8, R12, R13, R17: 10k; R_0201_0603Metric; LCSC C106225
R11, R16: 52.3k; R_0201_0603Metric; LCSC C2575555
R14, R15: 100k; R_0201_0603Metric; LCSC C106224
TP1, TP2, TP3: TestPoint; TestPoint_Pad_D1.0mm
TP6, TP7: B+; SolderPad_1.2x2.0mm
TP8, TP10, TP12: M+; SolderPad_1.2x2.0mm
TP9, TP11, TP13: M-; SolderPad_1.2x2.0mm
TP14: gnd; SolderPad_1.2x2.0mm
TP15: 5v; SolderPad_1.2x2.0mm
TP16: S; SolderPad_1.2x2.0mm
U1: ESP32-C3; QFN-32-1EP_5x5mm_P0.5mm_EP3.7x3.7mm
U2: LSM6DS3TR-C; LGA-14_3x2.5mm_P0.5mm_LayoutBorder3x4y; MPN LSM6DS3TR-C; LCSC Part C967633
U3: SX1281IMLTRT; QFN-24_L4.0-W4.0-P0.50-TL-EP2.6; LCSC Part C2151551
U4: TLV75533PDQNR; X2SON-4_L1.0-W1.0-P0.65-TL-EP; LCSC Part C2861882
U6, U10, U11: DRV8212DSGR; WSON-8_L2.0-W2.0-P0.50-TL-EP; MPN DRV8212DSGR; LCSC Part C2843766
U7: NZ9F6V2ST5G; SOD-923_L0.8-W0.6-LS1.0-RD; MPN NZ9F6V2ST5G; LCSC Part C896533
U8: TPS63070RNMR; VQFN-15_L3.0-W2.5-P0.50-BL; MPN TPS63070RNMR; LCSC Part C109322
U9: TS2306A 240GF MSM 9_C2976675; SW-SMD_4P-L3.0-W2.0-P0.85-LS3.5; LCSC Part C2976675
X1: CJ17-400001010B20; CRYSTAL-SMD_4P-L1.6-W1.2-BL; LCSC Part C2875272

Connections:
+3V3: C4.1, C5.1, C6.1, C9.1, C11.1, C12.1, C13.1, C14.1, C15.1, C17.1, C18.1, C23.1, C24.1, C29.1, C30.1, C40.1, C41.1, C43.1, D1.2 (VDD), L3.2, OSC1.4 (VDD), R3.1, R4.1, R5.2, R6.1, R8.1, U1.11 (VDD3P3_RTC), U1.17 (VDD3P3_CPU), U1.18 (VDD_SPI), U1.31 (VDDA), U1.32 (VDDA), U2.5 (VDDIO), U2.8 (VDD), U3.11 (VBAT_IO), U3.15 (VBAT), U4.1 (OUT), U6.7 (MODE), U6.8 (VCC), U10.7 (MODE), U10.8 (VCC), U11.7 (MODE), U11.8 (VCC)
+5V: C37.1, C38.1, R16.2, TP15.1 (1_1), U4.3 (EN), U4.4 (IN), U8.7 (Vout)
+BATT: C32.1, C33.1, C34.1, C35.1, C42.1, Q2.5 (D), Q2.6 (D), Q2.7 (D), Q2.8 (D), Q2.9 (D), R11.2, R15.2, U6.1 (VM), U8.12 (Vin), U10.1 (VM), U11.1 (VM)
/ESP32-C3 + SX1281 Core (UFL)/BOOT: R4.2, TP3.1 (1_1), U1.15 (GPIO9), U9.1
/ESP32-C3 + SX1281 Core (UFL)/BUSY: U1.8 (GPIO3), U3.7 (BUSY)
/ESP32-C3 + SX1281 Core (UFL)/CHIP_EN: C28.1, R5.1, U1.7 (CHIP_EN), U3.3 (NRESET)
/ESP32-C3 + SX1281 Core (UFL)/DIO1: U1.5 (XTAL_32K_N), U3.8 (DIO1)
/ESP32-C3 + SX1281 Core (UFL)/IMU_CS: R8.2, U1.6 (GPIO2), U2.12 (CS)
/ESP32-C3 + SX1281 Core (UFL)/LED: D1.4 (DIN), R3.2, U1.14 (GPIO8)
/ESP32-C3 + SX1281 Core (UFL)/LEFT_EN: U1.26 (GPIO19), U6.5 (IN2/EN)
/ESP32-C3 + SX1281 Core (UFL)/LEFT_PH: U1.25 (GPIO18), U6.6 (IN1/PH)
/ESP32-C3 + SX1281 Core (UFL)/MISO: U1.10 (MTDI), U2.1 (SDO/SA0), U3.16 (MISO_TX)
/ESP32-C3 + SX1281 Core (UFL)/MOSI: U1.9 (MTMS), U2.14 (SDA), U3.17 (MOSI_RX)
/ESP32-C3 + SX1281 Core (UFL)/NSS: R6.2, U1.13 (MTDO), U3.19 (NSS_CTS)
/ESP32-C3 + SX1281 Core (UFL)/RIGHT_EN: TP1.1 (1_1), U1.28 (U0TXD), U10.5 (IN2/EN)
/ESP32-C3 + SX1281 Core (UFL)/RIGHT_PH: TP2.1 (1_1), U1.27 (U0RXD), U10.6 (IN1/PH)
/ESP32-C3 + SX1281 Core (UFL)/SCK: U1.12 (MTCK), U2.13 (SCL), U3.18 (SCK_RTSN)
/ESP32-C3 + SX1281 Core (UFL)/VSENSE: R11.1, R12.2, U1.4 (XTAL_32K_P)
/ESP32-C3 + SX1281 Core (UFL)/WEAPON_EN: TP16.1 (1_1), U1.16 (GPIO10), U11.5 (IN2/EN)
/ESP32-C3 + SX1281 Core (UFL)/WIFI: AE1.1, C21.1, L2.1
/ESP32-C3 + SX1281 Core (UFL)/XTAL_N: C3.1, U1.29 (XTAL_N), X1.3
/ESP32-C3 + SX1281 Core (UFL)/XTAL_P: L1.2, U1.30 (XTAL_P)
GND: C1.2, C3.2, C4.2, C5.2, C6.2, C9.2, C11.2, C12.2, C13.2, C14.2, C15.2, C17.2, C18.2, C20.1, C21.2, C22.2, C23.2, C24.2, C25.2, C26.1, C27.2, C28.2, C29.2, C30.2, C32.2, C33.2, C34.2, C35.2, C36.1, C37.2, C38.2, C40.2, C41.2, C42.2, C43.2, D1.3 (GND), FL1.2 (GND), FL1.4 (GND), OSC1.1 (GND), OSC1.2 (GND), R12.1, R13.1, R14.2, R17.1, TP7.1 (1_1), TP14.1 (1_1), U1.33 (GND), U2.2 (SDx), U2.3 (SCx), U2.6 (GND), U2.7 (GND), U3.13 (GND), U3.20 (GND), U3.21 (GND), U3.23 (GND), U3.24 (GND), U3.25 (EP), U4.2 (GND), U4.5 (EP), U6.4 (GND), U6.9 (EP), U8.4 (GND), U8.6 (FB2), U8.10 (PGND), U8.15 (Vsel), U9.2, U10.4 (GND), U10.9 (EP), U11.4 (GND), U11.6 (IN1/PH), U11.9 (EP), X1.2 (GND), X1.4 (GND)
unnamed: C1.1, L1.1, X1.1
unnamed: C25.1, L3.1, U1.2 (VDD3P3), U1.3 (VDD3P3)
unnamed: FL1.1 (IN), U3.22 (RFIO)
unnamed: AE2.1, FL1.3 (OUT)
unnamed: C19.1, OSC1.3 (Out_Put)
unnamed: Q2.4 (G), R13.2, U7.2 (A)
unnamed: C22.1, L2.2, U1.1 (LNA_IN)
unnamed: C20.2, C26.2, L4.1, U3.2 (VDD_IN), U3.12 (DCC_FB)
unnamed: L4.2, U3.14 (DCC_SW)
unnamed: C27.1, U3.1 (VR_PA)
unnamed: C19.2, U3.4 (XTA)
unnamed: TP9.1 (1_1), U6.2 (OUT1)
unnamed: TP8.1 (1_1), U6.3 (OUT2)
unnamed: Q2.1 (S), Q2.2 (S), Q2.3 (S), TP6.1 (1_1), U7.1 (K)
unnamed: R15.1, U8.14 (EN)
unnamed: R16.1, R17.2, U8.5 (FB)
unnamed: L6.1, U8.11 (L1)
unnamed: L6.2, U8.9 (L2)
unnamed: R14.1, U8.1 (PS/SYNC)
unnamed: C36.2, U8.3 (Vaux)
unnamed: TP11.1 (1_1), U10.2 (OUT1)
unnamed: TP10.1 (1_1), U10.3 (OUT2)
unnamed: TP13.1 (1_1), U11.2 (OUT1)
unnamed: TP12.1 (1_1), U11.3 (OUT2)

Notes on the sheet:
GPIO0 GPIO1
SX1281 + ESP32-C3 + LDO + RGB LED (full ELRS)
GPIO21 GPIO20
Motors
LDO
BUCK/BOOST
IMU
GPIO4 GPIO5 GPIO6 GPIO7
SX1281 radio
ESP32C3 MCU
07/06/2026
GND on pin 5 unconnected as per SX128x datasheet when using TCXO
1u for VDD_SPI
50 Ohm matching pi filter as per ESP schematic checklist. Exact components TBD Use RF grade components here

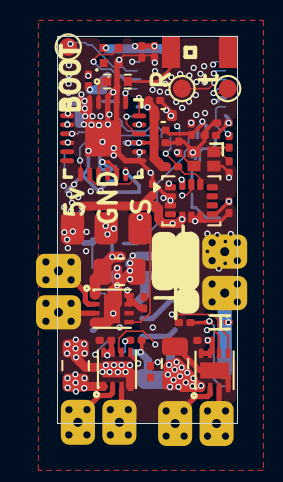
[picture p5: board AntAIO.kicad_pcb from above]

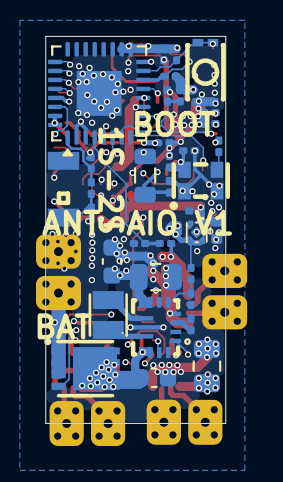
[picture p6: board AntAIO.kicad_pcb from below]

Board: 6 copper layers, 10.0 x 21.5 mm, 84 parts (35 on the bottom side), 47 nets.

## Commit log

2026-05-08 OpenRX Lite (UFL + molex)
    [OpenRX-Lite-UFL.kicad_pcb, OpenRX-Lite.kicad_pcb, OpenRX-Lite.kicad_sch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]
2026-05-13 add via testing board
    [OpenRX-Gemini-sameside.kicad_pcb, OpenRX-Gemini.kicad_pcb]
2026-06-06 docs: standardized 3D board renders for all RX variants (front/back)
2026-06-07 docs: populate DOC_* text variables for all RX variants
    Set DOC_NAME/HANDLE/VARIANT/TAGLINE/FIRMWARE/PROTOCOL/MCU/INPUT/RATING in
    each variant .kicad_pro, derived from the schematics and ELRS target JSON,
    matching the sibling OpenDrone repos' convention.
2026-06-07 docs: reconcile README against schematics, add DESIGN_NOTES + all-variant renders
    - README rewritten against schematic/netlist ground truth (OpenFC-Lite-Mini-style
    layout, all four variants' front/back renders side-by-side).
    - Corrected antenna roles: AE1 (2450AT18A100E ceramic) is the ESP32-C3 Wi-Fi/OTA
    antenna (net WIFI) on every variant; the ELRS link antenna is FL1-OUT's load —
    47948-0001 chip antenna on Lite, U.FL on Lite-UFL/Mono/Gemini.
    - Pad pinout + per-variant pin map derived from netlists and ELRS target JSON.
    - Corrected: two distinct radio TCXOs (52 MHz SX1281 / 32 MHz LR1121); only Gemini
    has a tactile button; per-variant LED GPIO.
    - DESIGN_NOTES.md mirrors the on-can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
2026-06-07 docs: via-free board renders
    Re-render top/bottom board images with vias removed for a cleaner look.
    KiCad cannot render tented vias, so vias were temporarily stripped via the
    pcbnew API for rendering only; source .kicad_pcb files are unchanged.
2026-06-07 docs: re-render boards without floor shadows
    Re-render top/bottom images at basic quality so the soldermask floor
    shadow halo is gone. Vias still stripped for the render only (via pcbnew),
    source .kicad_pcb files unchanged.
2026-06-07 docs: render boards without solder paste
    Strip the solder-paste layer (and vias) for the render only so SMD pads
    show as clean copper instead of gray paste deposits. Source .kicad_pcb
    files unchanged.
2026-06-07 docs: remove DESIGN_NOTES, trim README boilerplate
    - Delete DESIGN_NOTES.md (and its gitignore exception)
    - Drop the Manufacturing / production-export section
    - Remove the canonical-reference boilerplate blurb
    - ESC boards: AM32 bootloader ships pre-loaded, firmware flashed via am32.ca
2026-06-10 fab/BOM/cpl as ordered
    [OpenRX-all-B_Cu.gbr, OpenRX-all-B_Mask.gbr, OpenRX-all-B_Paste.gbr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]
2026-06-10 updated HW files as ordered
    [lr1121.kicad_sch]
2026-06-19 feat(OpenRX-Lite): convert to AntAIO antweight battlebot AIO
    Extend OpenRX-Lite (ESP32-C3 + SX1281 ELRS RX) into an integrated
    1–2S antweight combat-robot controller in the Malenki-Nano style:
    - Triple brushed-DC ESC: 3× DRV8212 (U6/U10 drive, U11 weapon)
    - 6-axis IMU LSM6DS3TR-C (U2) on the shared radio SPI bus
    - Power: TPS63070 buck-boost (+BATT→5V) + TLV75533 LDO (→3V3),
    AON7407 reverse-polarity P-FET
    - New footprints/3D: DFN-8, WSON-8, VQFN-15, LGA-14, SOD-923, IND 2.0×1.6
    - Add part datasheets (DRV8212, LSM6DS3TR-C, TPS63070, AON7407)
    - CHANGELIST.md: verified open/done items
    - REVIEW.md: multi-agent pin/datasheet/electrical design review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
    [OpenRX-Lite.kicad_pcb, OpenRX-Lite.kicad_sch, esp32c3_sx1281_lite.kicad_sch]
2026-06-19 docs: rewrite README for AntAIO battlebot AIO + add board renders
    - README now describes the AntAIO antweight combat-robot controller
    (ELRS RX + LSM6DS3 IMU + triple DRV8212 ESC) built on the OpenRX-Lite core
    - New front/back board renders (antaio-front.png / antaio-back.png)
    - Prominent prototype/safety status; links REVIEW.md + CHANGELIST.md
2026-06-19 docs: dimensioned board renders + fix Malenki link & board size
    - Re-render front/back on dark engineering background; front now carries
    width/length dimension arrows (10.00 × 21.50 mm)
    - Correct board size in README (was wrongly ~32×32 mm — actual Edge.Cuts
    outline is 10.00 × 21.50 mm)
    - Fix Malenki Nano product link (turnabot.com)
2026-06-19 refactor: port repo from OpenRX-Lite fork to standalone AntAIO (#1)
    Convert the forked OpenRX receiver repo into the standalone AntAIO
    combat-robot AIO board.
    Rename / restructure:
    - KiCad project OpenRX-Lite -> AntAIO, moved to hardware/
    (AntAIO.kicad_{pro,sch,pcb}); .kicad_pro JSON, DOC_* text vars and fab
    archive name updated; 154 embedded (project "AntAIO") symbol-instance
    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
    [AntAIO.csv, AntAIO.kicad_pcb, AntAIO.kicad_sch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]
